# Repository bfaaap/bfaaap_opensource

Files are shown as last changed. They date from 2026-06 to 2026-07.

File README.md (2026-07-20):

# bFaaaP — a foot‑free piano pedal you can build 🎹

> 🌐 **English** · [日本語](i18n/ja/README.md) · [Deutsch](i18n/de/README.md)



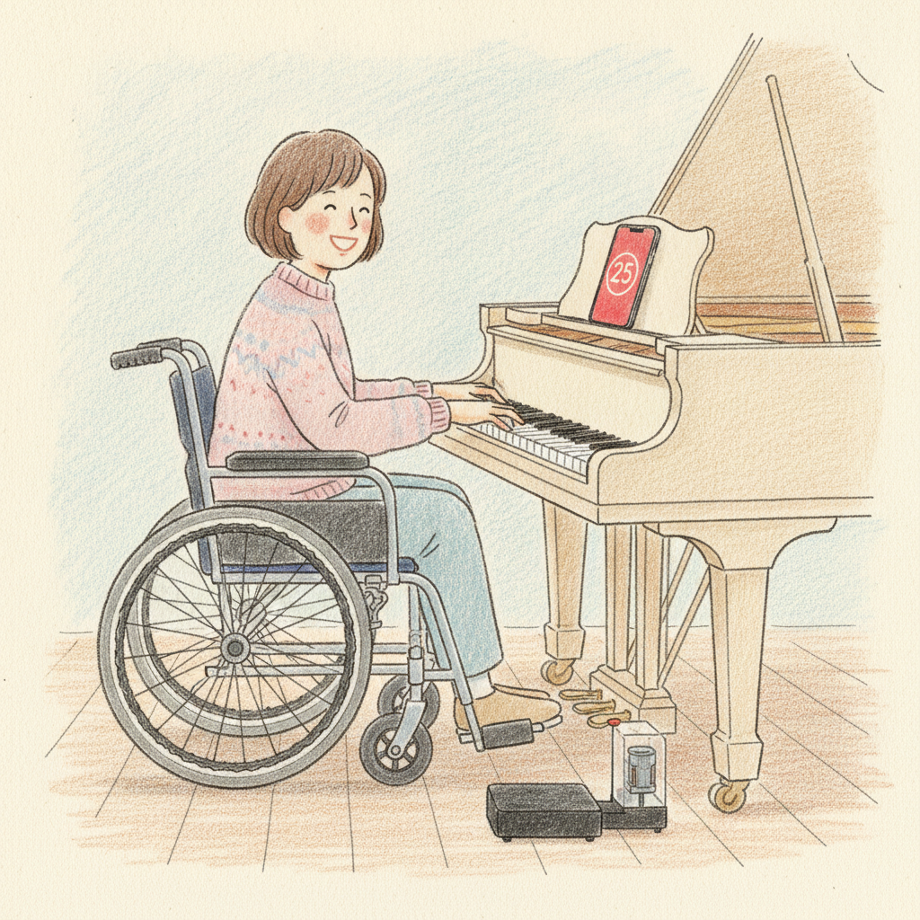
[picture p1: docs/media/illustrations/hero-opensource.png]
bFaaaP — play the pedal with a tilt of your head


> **bFaaaP** — *(**b**arrier‑**F**ree **a**ssist **a**s **a** **P**edal)* — is an **AI
> assistive piano‑pedal system**. Tilt your head a little and the sustain pedal goes down —
> **no feet needed.** An iPhone/iPad reads your head angle with on‑device AI and sends it over
> Bluetooth to a small device that presses (or switches) the piano's pedal.

It exists so that people who can't easily use a foot pedal — players with limb disabilities,
small children, the elderly, even a user with a tracheostomy — can play the piano with the
full expressive power of the pedal. And it's **open source**: this repository has everything
to build the device and run the controller **yourself**.

### Start here
🌱 **New?** → [**The bFaaaP story**](docs/story.md) · [How it works](docs/how-it-works.md) · [Glossary](docs/GLOSSARY.md)
🔧 **Make one** → [**Build it yourself**](docs/build/) (iOS · Pro · Switch)
🗂 **Find any source** → [Source map](docs/SOURCE-MAP.md) — which file / figure / code backs each topic
🙋 **Get help** → [Community Support](docs/ai-support.md) · 💛 [Support the project](SUPPORT.md)

> Status: this folder (`github_opensource/`) is the staging area being prepared for public
> release (see [`PUBLISHING-CHECKLIST.md`](PUBLISHING-CHECKLIST.md)). Docs are **English‑first**;
> Japanese & German will follow in `i18n/` subfolders.

---

## What is bFaaaP?

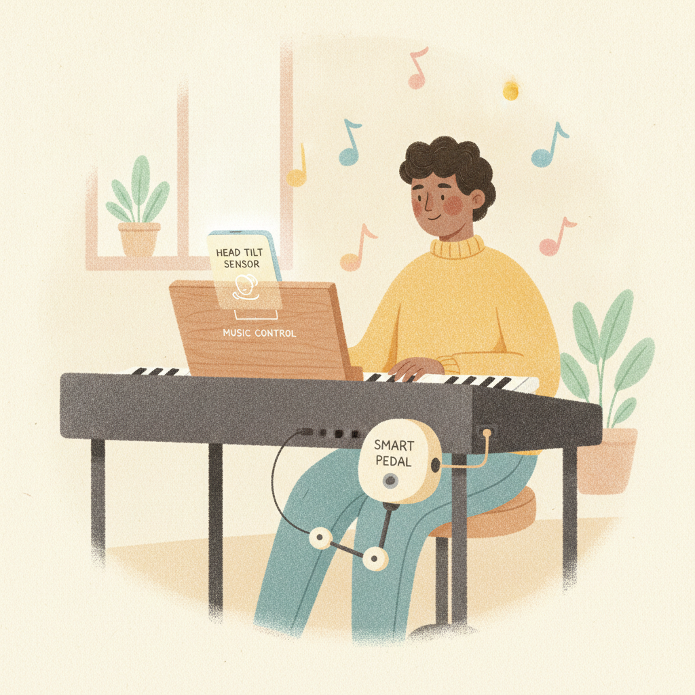
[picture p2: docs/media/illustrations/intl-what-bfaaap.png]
What is bFaaaP — a player using the head‑tilt sensor and smart pedal


A small head movement becomes a pedal press. You preset your own **offset (threshold)** — how far
to tilt — and a **multiplier**, and together they tune the pedalling to *you* — not just a crude
on/off. See [How it works](docs/how-it-works.md) for the friendly explanation.

## Two hardware lines, one app

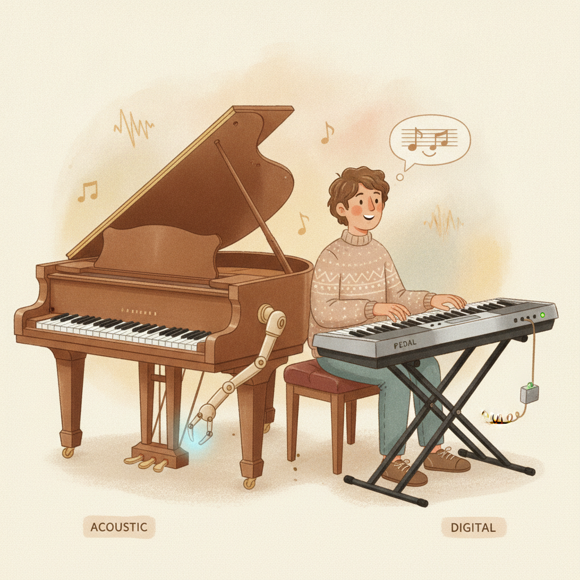
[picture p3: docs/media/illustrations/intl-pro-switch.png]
Pro for acoustic pianos, Switch for digital pianos


| Line | For | How it actuates |
|---|-----|---|
| 🎹 **bFaaaP Pro** | Acoustic pianos (**grand & upright**) | a **motor physically presses** the sustain pedal, anchored by an *airback* air‑cushion → [`device-pro-acoustic/`](device-pro-acoustic/) |
| 🎛️ **bFaaaP Switch** | **Electric pianos & keyboards** | plugs into the **sustain‑pedal jack** as an **electronic switch** (no motor/airback) → [`device-switch-electronic/`](device-switch-electronic/) |

The **same iOS app** ([`ios-app/`](ios-app/)) drives both lines; the Bluetooth protocol is identical.

## How it works

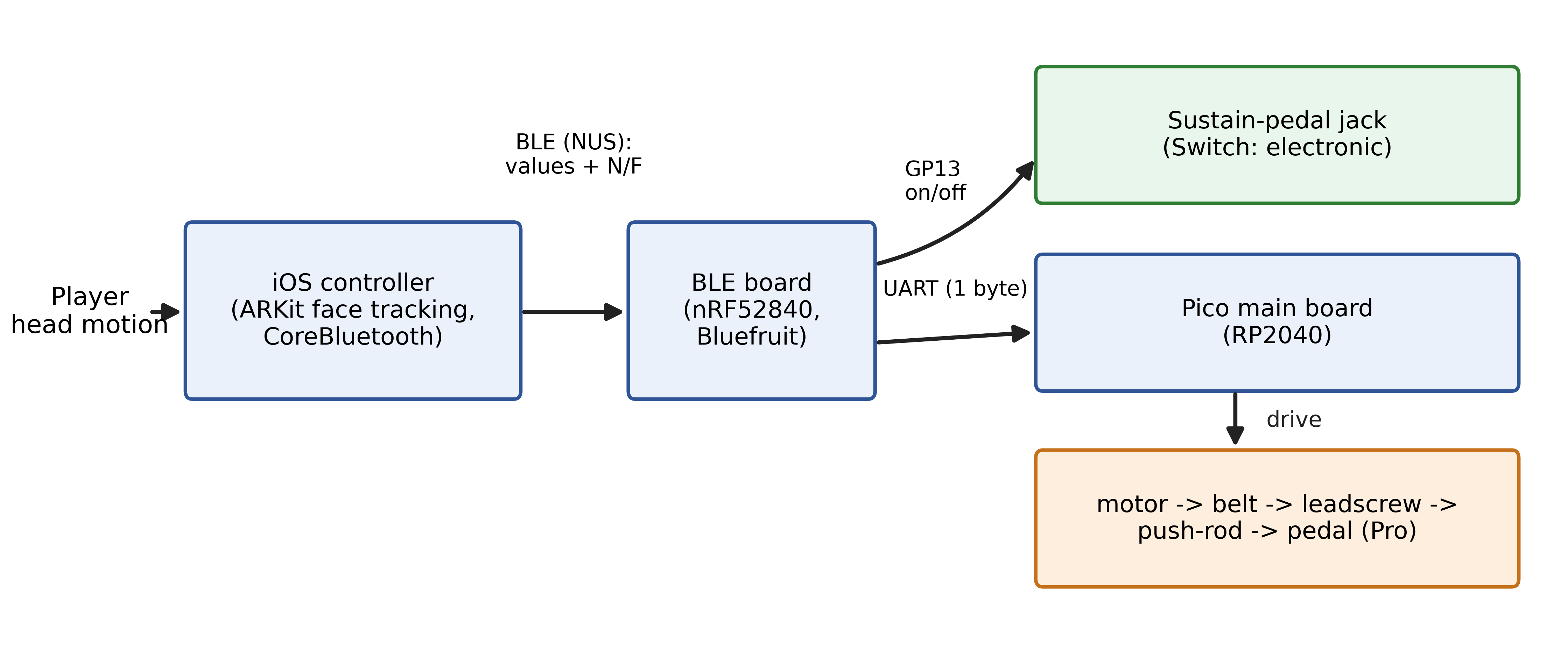
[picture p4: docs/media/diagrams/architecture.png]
System architecture


```
   Your head tilt
        │  ARKit / TrueDepth face tracking (iPhone/iPad AI)
        ▼
┌──────────────┐   BLE  "i00".."i99"   ┌─────────────────┐  UART  ┌──────────────┐  drive
│   iOS app    │ ────────────────────▶ │ BLE board nRF52  │ ─────▶ │  Pico RP2040 │ ─────▶ piano pedal
└──────────────┘                       └─────────────────┘        └──────────────┘
```

A key design point: ARKit produces head angles much faster than BLE should send them, so the
app **paces** the radio (a 100 ms timer + throttle) to keep the link solid — see
[`ios-app/DESIGN-HIGHLIGHTS.md`](ios-app/DESIGN-HIGHLIGHTS.md).

## Build it yourself

Open the **[Build hub](docs/build/)** and pick a track. The short version (Pro):

1. **Print & assemble** the mechanical parts — [`device-pro-acoustic/hardware/`](device-pro-acoustic/hardware/).
2. **Wire & flash** both boards — [`docs/toolchain/`](docs/toolchain/) (VS Code / PlatformIO / Arduino).
3. **Anchor** with the airback; set the travel limit.
4. **Build & install the iOS app** — [`ios-app/`](ios-app/) (your own signing team & bundle ID).
5. **Pair, calibrate, and play** — [`docs/operation/`](docs/operation/).

Stuck on any step? **[Ask in our community Q&A](docs/ai-support.md)** — the bFaaaP community and
team check each answer, so it's not instant.

### Bill of materials (overview, Pro line)
- iPhone / iPad with **TrueDepth** front camera (head tracking)
- **Raspberry Pi Pico** (main) + **nRF52840** BLE board (bridge)
- **IQ‑FORTIQ‑M42BLS‑100** motor *(reference v039B; EOL → closed‑loop **NEMA17‑class** successor
  under evaluation)*, belt‑coupled (**GT-2‑262 belt → T60/T60 pulleys, 1:1**) to a
  **vertical T10 lead‑screw** whose carriage drives a **push‑rod straight down** on the sustain
  pedal — all on a **2040 / 2080 / 4040 aluminium‑extrusion** frame
- **HX711** air‑pressure sensor, **2SK4017** MOSFET (pump), travel‑limit slider, **24 V PSU**
  *(self‑calibration uses motor **power**, not current — so supply voltage doesn't matter)*
- 3D‑printed parts (PLA+) + **airback** anchoring kit
- Full BOM & part numbers: [`device-pro-acoustic/hardware/PARTS-REFERENCE.md`](device-pro-acoustic/hardware/PARTS-REFERENCE.md)

> ⚠️ Some original parts are **EOL** (notably the IQ/Fortiq motor). Replacements & firmware tips:
> [`device-pro-acoustic/HARDWARE-AVAILABILITY.md`](device-pro-acoustic/HARDWARE-AVAILABILITY.md).

## The story, the people, the music 🎬

bFaaaP began in **2018** from one wheelchair user's wish to play the piano, and grew into a
team of engineers and musicians. Read the whole journey — with member introductions and **every
performance video** — in **[The bFaaaP story](docs/story.md)**.

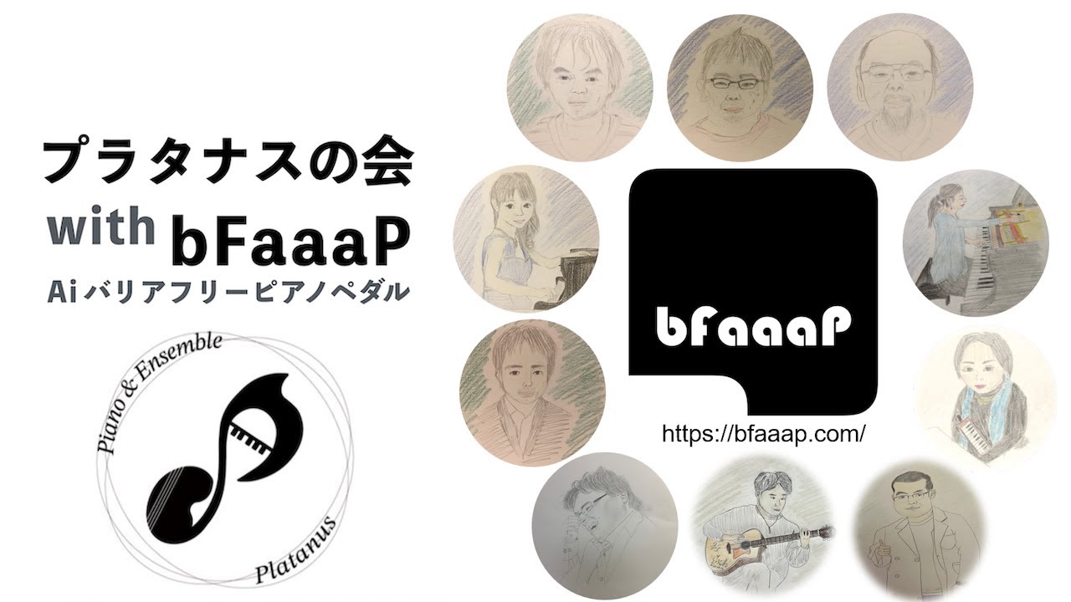
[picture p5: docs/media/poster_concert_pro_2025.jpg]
Platanus with bFaaaP — concert


- 📜 [History](docs/HISTORY.md) · 👥 [Members](docs/members/) · 💬 [Voices](docs/voices.md) · 🎥 [All videos](docs/videos/)
- ▶ **Best single demo** (grand piano, *with a setup walkthrough at 25:01*): <https://www.youtube.com/watch?v=V3cXeNW9jXY>

## 💛 Support

The devices aren't sold — your support keeps bFaaaP free and growing (development, community
support, parts/loaners, and inclusive concerts & lessons). See
[**SUPPORT.md**](SUPPORT.md) (PayPal now; Stripe — card / Apple Pay / Google Pay — coming) or use
the **Sponsor** button on this repo.

## 📣 Poster & events

Spread the word — here is the bFaaaP open‑source poster (front & back). Please feel free to print and share it.

<p align="center">
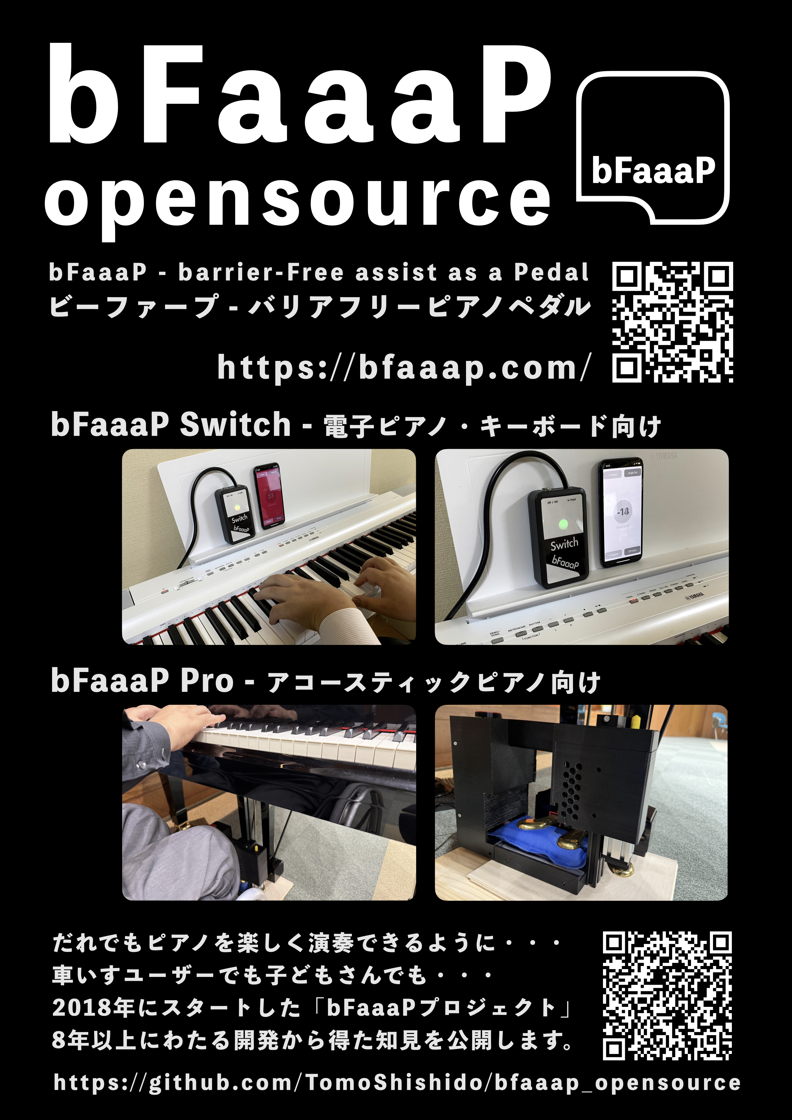
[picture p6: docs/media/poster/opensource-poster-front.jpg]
bFaaaP open‑source poster, front — the project, the Switch and Pro devices, and the QR codes
  
  <a href="docs/media/poster/opensource-poster-back.jpg">bFaaaP open‑source poster, back — the story since 2018, the 2025 Suzukake concert, and how to join</a>
</p>

<p align="center"><sub>Poster design: <b>Masahiro Ootaki</b> (Ootaki Architects Office)</sub></p>

> 📅 Thanks to the kind support of the **Tokyo Women's Choral Society**, this poster will be handed out at their **"Composer Exhibition Series Vol.6: Hideki Chihara"** concert on **Friday, July 31, 2026**. We're grateful for the chance to share our story — [concert details](https://tokyowomens-cs.website/2026/05/12/composerexhibitionseries-vol6-hidekichihara/).

## Repository layout

| Folder | Contents |
|---|---|
| [`ios-app/`](ios-app/) | iOS controller app — code, design notes, build guide, sanitized `src/`. Drives both lines. |
| [`device-pro-acoustic/`](device-pro-acoustic/) | **Pro** (acoustic): firmware, hardware (`cad/`, `3d-print/`, `airback/`, `schematic/`), motor info, assembly. |
| [`device-switch-electronic/`](device-switch-electronic/) | **Switch** (electric/keyboard): electronic‑sustain design (in progress). |
| [`docs/`](docs/) | Story, how‑it‑works, glossary, build hub, community support, architecture, operation, toolchain, videos, members, history. |
| [`bfaaap_arxiv_latex/`](bfaaap_arxiv_latex/) | The research **arXiv preprint** (LaTeX). |
| [`bfaaap_patent_info/`](bfaaap_patent_info/) | Plain‑language patent guide + prosecution files. |

## License

This project is **multi‑licensed by layer (adopted).** Full, verbatim texts are in
[`LICENSES/`](LICENSES/); the split (see [`LICENSE`](LICENSE)) is — **Apache‑2.0** (software: iOS
app, firmware; explicit patent grant), **CERN‑OHL‑W‑2.0** (hardware: CAD, 3D‑print, schematic),
**CC‑BY‑4.0** (documentation). Third‑party components keep their own licenses (e.g. the IQ module
library). Imported contributor materials (schematic / CAD / photos) are included **with consent**
(all members have consented — see [`PUBLISHING-CHECKLIST.md`](PUBLISHING-CHECKLIST.md)).

## 📄 Research

A LaTeX **arXiv** preprint (`main.tex`) is in [`bfaaap_arxiv_latex/`](bfaaap_arxiv_latex/). It
frames bFaaaP as inclusive design / human–machine interaction whose inventive core is a
**quantitative, user‑tunable head‑angle control law**, validated by a **human‑subject clinical
evaluation (APEE)**. Authors: T. Shishido (corresponding), M. Ootaki, H. Narusawa. *(A peer‑reviewed ACM
TACCESS version is maintained privately.)*

## Patents, trademark & design

The control method — a quantitative, user‑tunable control law in which the player presets an
angular **dead‑zone (offset)** (a range within which the actuator is not driven) and a
**multiplier**, which together fix a secondary, temporal **response speed** (how fast the actuator
follows the head past the dead‑zone) — is patented. **Two patents are in force in Japan**, with an English **PCT**
as priority basis:

| Kind | Number | Title | Link |
|---|---|---|---|
| Patent (JP) | **特許第6726319号** — JP 6726319 B2 | Auxiliary pedal system | <https://patents.google.com/patent/JP6726319B2/en> |
| Patent (JP) | **特許第7004771号** — JP 7004771 B2 | Device controller | <https://patents.google.com/patent/JP7004771B2/en> |
| PCT (EN, priority) | **WO 2019/176164** | Auxiliary pedal system | <https://patentscope.wipo.int/search/en/detail.jsf?docId=WO2019176164> |

Inventors: H. Narusawa, M. Ootaki, T. Shishido, K. Yamaguchi, D. Tokushige. **bFaaaP®** is a
registered trademark; the glasses‑mounted motion sensor is a registered design. Full prosecution
file & a plain‑language guide: [`bfaaap_patent_info/`](bfaaap_patent_info/).

### Patent licensing
Licensing generally **depends on the intended embodiment**. However, **for uses with a genuinely
public, open purpose the authors intend to grant a licence free of charge** — in particular **for
products/services (even commercial) that help people with disabilities participate more
inclusively, bFaaaP patent licensing is, as policy, free.** If that fits your use, please contact
**Tomoyuki Shishido** (ORCID <https://orcid.org/0000-0002-8944-2088>).

## Credits

Developed by **Tomoyuki Shishido** and the bFaaaP / **Platanus** members (incl. M. Ootaki,
H. Narusawa, and others — see [Members](docs/members/)). The iOS app is **free** on the App Store as
**bFaaaP Pro & Switch**. Illustrations by **Saki Shiokawa** and the bFaaaP project (AI‑assisted).

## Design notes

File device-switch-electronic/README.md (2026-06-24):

# bFaaaP Switch — for electric pianos & keyboards

The **Switch** line targets **electric pianos and keyboards**. Instead of a motor
physically pressing an acoustic pedal (the Pro approach), it actuates the
instrument's sustain **electronically**: it plugs into the digital piano /
keyboard's **sustain‑pedal jack** and acts as the pedal **switch** (closing /
opening the sustain circuit on command).

Because there is **no motor, no lead screw, and no airback**, the Switch is much
simpler than the Pro — essentially the **BLE board on its own** (an **Adafruit
ItsyBitsy nRF52840 Express**), using its direct on/off output (the firmware drives
`GP13` on `N`/`F`). The standalone Switch firmware now lives here in
[`firmware/`](firmware/) (the same nRF52 BLE-board code as the Pro, minus the
motor-board bridge). The board's **onboard DotStar RGB LED** shows the engage
state as a colour on the device itself (mirroring the app's white→red indicator).

The **same iOS app** drives this line — identical head‑angle tracking and BLE
protocol as the Pro (`N` engage / `F` release; `iNN` is unused for a simple
on/off switch). When the player tilts past the threshold the app's indicator
turns **red** and the sustain engages; head up → released.

> Demo (electric piano): <https://www.youtube.com/watch?v=Im4jsed1tJQ>
> · Project site: <https://bfaaap.com>

## How it works

```
 iOS app ──BLE (N / F)──▶ BLE board (nRF52) ──GP13 on/off──▶ MOSFET
                                                              │
                                                              ▼
                                              digital piano sustain‑pedal jack
```

A **ROHM `RU1J002YN`** N-channel (logic-level) **MOSFET** on the BLE board's `GP13`
output bridges the sustain jack's contacts (confirmed by Narusawa, 2026‑06‑24 —
**no series resistor**) — the same wiring most digital pianos expect from a normal
momentary sustain pedal (tip/sleeve). Polarity / normally‑open vs normally‑closed
is handled by the on‑type / off‑type setting (`n` / `f`).

## Connection & certification

- The device cable ends in a **6.3 mm 2‑pole (TS) phone plug**; it plugs into the
  electric piano's **SUSTAIN** pedal jack (3‑pedal "PEDAL UNIT" jacks differ).
- The shipped Switch device carries Japan radio certification **技適 R018‑180280**.
- **On‑type / Off‑type**: some pianos invert the sustain logic — flip it with the
  app's On/Off button.
- Full end‑user steps: [`../docs/user-manual/`](../docs/user-manual/) ·
  manual video <https://youtu.be/XOVENtBsOp4>.

## Status

The **firmware is now in the repo** — see [`firmware/`](firmware/) for the
standalone nRF52 sketch (`bFaaaPSW_20211007_for_ex_fs_J_13_ymc`), its full BLE
command protocol, the GP13 on/off behaviour, channel selection, and power
management. The **hardware** around it is now specified too:

```
device-switch-electronic/
├── firmware/    ✅ standalone BLE-board firmware (on/off via GP13)   ← added 2026-06-24
├── hardware/    ✅ RU1J002YN low-side MOSFET + reference schematic   ← added 2026-06-24
└── assembly/    ◑ AI-draft enclosure: parametric SCAD + STL + drawing ← added 2026-06-24
```

**Confirmed by Narusawa (2026‑06‑24):** board = **ItsyBitsy nRF52840 Express**; the
GP13 switching element is a **ROHM `RU1J002YN`** N-channel logic-level MOSFET (no
series resistor); **no A1 button** — power on / wake with **RESET**; powered by
**2× AA cells** (battery level shown by the **DotStar dimming**); the 2021‑10‑07
firmware is **final**. The Switch hardware is now **fully specified** — the
reference schematic (RU1J002YN low‑side switch) is in [`hardware/`](hardware/), and
an **AI-draft 3D-printable enclosure** (parametric OpenSCAD + STL + drawing) is in
[`assembly/`](assembly/) — *untested; verify against your parts before printing*.

See the shared [`../docs/architecture/`](../docs/architecture/) for the BLE
protocol and [`../ios-app/`](../ios-app/) for the controller.

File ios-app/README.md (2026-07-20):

# iOS controller app (bFaaaP Pro & Switch)

The SwiftUI app that reads the user's head angle (ARKit / TrueDepth) and streams
it over Bluetooth LE to the pedal device.

**One app, both hardware lines.** The same iOS app drives **bFaaaP Pro** (for
acoustic pianos) and **bFaaaP Switch** (for electric pianos / keyboards). The
BLE protocol is identical; only the device hardware differs.

## Contents

| File / folder | What |
|---|---|
| [`CODE-STRUCTURE.md`](CODE-STRUCTURE.md) | How the Swift files fit together + data flow |
| [`DESIGN-HIGHLIGHTS.md`](DESIGN-HIGHLIGHTS.md) | The clever bits (AR↔BLE timing, hysteresis, …) |
| [`BLE-CONNECTION-FLOW.md`](BLE-CONNECTION-FLOW.md) | Flowcharts: recognize device by name (4 channels), connect, and the sync→async handoff |
| [`BUILD.md`](BUILD.md) | How to build it yourself (set your own team & bundle ID) |
| [`src/`](src/) | The Xcode project (sanitized: blank team, placeholder bundle ID) |
| [`app-store/`](app-store/) | App Store listing info, icon & screenshots ([on the App Store](https://apps.apple.com/app/id1545866059)) |

## App facts

| Item | Value |
|---|---|
| Display name | **bFaaaP Pro & Switch** (on‑device + App Store; Xcode target stays `bFaaaPSwitch1`) |
| Bundle ID (in repo) | `com.example.bfaaap` (placeholder — set your own) |
| Min iOS | 14.5 |
| Language / UI | Swift 5, SwiftUI |
| Key frameworks | ARKit (face tracking), CoreBluetooth (BLE) |
| Requires | Device with a TrueDepth front camera |

Start with [`CODE-STRUCTURE.md`](CODE-STRUCTURE.md), then
[`DESIGN-HIGHLIGHTS.md`](DESIGN-HIGHLIGHTS.md), then build via [`BUILD.md`](BUILD.md).

---
**License (adopted):** the iOS app source is released under the **Apache License 2.0** (explicit patent grant). See [`../LICENSE`](../LICENSE).

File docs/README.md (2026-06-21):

# Documentation (shared)

Cross‑cutting docs that apply to both hardware lines and the iOS app.

- [`architecture/`](architecture/) — how the system works end to end: signals,
  BLE / Nordic UART protocol, the AR→BLE timing model.
- [`operation/`](operation/) — how to set up and operate the system day to day.
- [`toolchain/`](toolchain/) — VSCode‑centric guide to **flashing the boards**
  (nRF52 + RP2040), testing/running, and **3D‑print slicing**.
- [`user-manual/`](user-manual/) — end‑user manual (connect, channel, on/off‑type,
  angle threshold) adapted from the public manual.
- [`HISTORY.md`](HISTORY.md) — how bFaaaP started (2018) and evolved.
- [`members/`](members/) — the people behind bFaaaP (with caricatures).
- [`videos/`](videos/) — guide to all YouTube videos, by category (concerts,
  setup, manual, promotion), newest first.
- [`../bfaaap_patent_info/`](../bfaaap_patent_info/) — the **patents**: the English
  PCT, the two granted Japanese patents, prior‑art citations, and a plain‑language
  [patent guide](../bfaaap_patent_info/general_description/README.md) (procedure
  diagrams, dated prosecution histories, academic take‑aways).

Line‑specific build/assembly lives with each device, e.g.
[`../device-pro-acoustic/assembly/`](../device-pro-acoustic/assembly/).

iOS code documentation is in [`../ios-app/`](../ios-app/)
(`CODE-STRUCTURE.md`, `DESIGN-HIGHLIGHTS.md`, `BUILD.md`).

> Localization: English first; Japanese and German versions are planned in
> separate `i18n/` subfolders.

---
**License (adopted):** documentation is released under **CC‑BY‑4.0**. See [`../LICENSE`](../LICENSE).

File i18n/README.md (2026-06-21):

# Translations / 翻訳 / Übersetzungen

The project documentation is written **English‑first** (repo root + [`../docs/`](../docs/)).
Translated mirrors live here:

- 🇯🇵 **日本語** → [`ja/`](ja/) — start at [`ja/README.md`](ja/README.md)
- 🇩🇪 **Deutsch** → [`de/`](de/) — start at [`de/README.md`](de/README.md)

Each translated page has a 🌐 language switcher at the top. **Images, figures, code, CAD, and
schematics are not translated** — the translated pages link back to the shared assets in
[`../docs/media/`](../docs/media/) and the source folders, so there is a single source of truth.

> Translations are maintained by hand (kept in step with the English originals). If a page
> isn't translated yet, its links fall back to the English version.

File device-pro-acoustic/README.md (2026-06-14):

# bFaaaP Pro — pedal driver for acoustic pianos

The **Pro** device physically presses an acoustic piano's **sustain (damper)
pedal** on command from the iOS app. A servo motor pushes the pedal; a 3D‑printed
frame holds everything in place over the pedals; an **airback** anchoring
mechanism keeps the whole unit from sliding under the motor's reaction force.

> For electric pianos / keyboards, see the sibling line
> [`../device-switch-electronic/`](../device-switch-electronic/) (planned).

## Contents

| Folder | What |
|---|---|
| [`firmware/`](firmware/) | RP2040 / Raspberry Pi Pico firmware + the IQ motor library |
| [`hardware/`](hardware/) | Mechanical design: `cad/` (FreeCAD), `3d-print/` (STL/3MF), `airback/`, **`schematic/`** (circuit), **`reference/`**, `enclosure-labels/` |
| [`hardware/PARTS-REFERENCE.md`](hardware/PARTS-REFERENCE.md) | **Authoritative parts list** (boards, motor, connectors) with vendor links |
| [`motor/`](motor/) | Which motor to use + links to vendor docs |
| [`assembly/`](assembly/) | Build guide & bill of materials |
| [`HARDWARE-AVAILABILITY.md`](HARDWARE-AVAILABILITY.md) | ⚠️ EOL parts (IQ motor) + current replacements + firmware‑adaptation tips + links |
| [`DISCORD-FINDINGS.md`](DISCORD-FINDINGS.md) | Engineering summary from the team Discord + co‑author Q&A (parts, calibration, dev env, next‑gen ideas) |

## How a press happens

1. The iOS app sends `N` (engage) / `iNN` (amount) / `F` (release) over BLE.
2. The Pico firmware drives the **IQ / Fortiq** servo motor to push the sustain
   pedal proportionally.
3. The **airback** (inflated once at setup) keeps the unit anchored so the motor
   pushes the pedal — not itself — away. See
   [`hardware/airback/`](hardware/airback/).

See [`../docs/architecture/`](../docs/architecture/) for the signal/BLE detail
and [`../docs/operation/`](../docs/operation/) for how to operate it.

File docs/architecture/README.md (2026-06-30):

# Architecture

> 🌐 **English** · [日本語](../../i18n/ja/docs/architecture/README.md) · [Deutsch](../../i18n/de/docs/architecture/README.md)

## Signal chain

1. **Head tracking (iOS).** The controller app uses ARKit `ARFaceTrackingConfiguration`
   (TrueDepth camera) to read the user's head pitch angle.
2. **Mapping.** The head angle, minus the user's **offset** (dead‑zone), is multiplied by a user
   **"multiplier"** (slider, 0–20) and clamped to `0–99`. The offset and multiplier together fix a
   secondary **response speed** (how fast the actuator follows the head past the dead‑zone) — the
   patented "key."
3. **Transmission (BLE).** The value is sent as an ASCII string `i00`–`i99` over a
   **Nordic UART Service (NUS)**. Engage/release transitions also send marker
   bytes `N` (on) and `F` (off).
4. **Actuation (device).** The Pico firmware parses the value and commands the
   **IQ / Fortiq** motor to press the sustain pedal proportionally.

## BLE details (observed)

| Item | Value |
|---|---|
| Service (NUS) | `6E400001-B5A3-F393-E0A9-E50E24DCCA9E` |
| Write (RX, app→device) | `6E400002-B5A3-F393-E0A9-E50E24DCCA9E` |
| Notify (TX, device→app) | `6E400003-B5A3-F393-E0A9-E50E24DCCA9E` |
| Also present | DFU `00001530-…`, Device Information `180A`, Battery `180F` |
| Advertised name | `bFaaaPSwitch_1` (renameable `_1`..`_4` for multiple devices/channels) |

The app filters on the advertised local name so it connects only to a
`bFaaaPSwitch_n` device and ignores other nearby peripherals.

## Payload format

- `iNN` — target value, `NN` = `00`..`99` (angle × multiplier, clamped).
- `N` — engage signal (pedal active).
- `F` — release signal (pedal returns to neutral).
- Values are streamed on a timer (~100 ms cadence in current firmware/app).

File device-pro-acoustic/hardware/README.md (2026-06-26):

# Hardware — bFaaaP Pro (acoustic)

The mechanical assembly that holds the motor over the piano's pedals, drives the
sustain pedal, and anchors itself against the reaction force.

```
hardware/
├── cad/               FreeCAD source files (.FCStd) — editable design
├── 3d-print/          Ready-to-print meshes (.stl) and slicer projects (.3mf)
├── airback/           Anchoring mechanism (air bag + pump + hand controller)
├── schematic/         Circuit schematic + block/power diagrams (by Taguchi)
├── reference-design/  AI-draft adaptable architecture + mechanical layout (simplified)
├── photos/            Real build photos (airback + drive unit; by Taguchi)
└── enclosure-labels/  Product / enclosure label artwork (review before publishing)
```

> 🧭 **New to the Pro?** Start with the **[`reference-design/`](reference-design/)** —
> an AI-draft, *adaptable* system architecture + mechanical layout that explains how the
> whole device fits together (and what you can simplify or swap).

> 📷 **Build photos** of the airback and drive unit are in
> [`photos/`](photos/) (from the team Discord).

> 📐 **Wiring:** a **single‑sheet KiCad schematic** of the whole Pro device (IQ /
> v039B reference generation) is in [`schematic/`](schematic/), together with the
> system block diagram and the power‑supply options. It gives the authoritative
> **Pico pin map** (BLE UART GP0/GP1; HX711 GP2/GP3; IQ‑motor serial GP4/GP5;
> air‑pump MOSFET GP12; slider potentiometer on **ADC0/GP26**) and the **two power
> rails (+5 V logic, +24 V motor)**.

## Major components

| Component | What it does | Where |
|---|---|---|
| **Controller board** | Raspberry Pi Pico (RP2040) + BLE (Nordic UART). Receives `iNN`/`N`/`F` and commands the motor. | [`../firmware/`](../firmware/) |
| **Motor** | **IQ‑FORTIQ‑M42BLS‑100** (100 W) — **current reference (v039B)**; EOL → successor is a **closed‑loop stepper with a DRV8825‑compatible interface** (DRV8825 itself = old standard module, early tests only). | [`../motor/`](../motor/) |
| **Drivetrain** | Motor → **GT-2‑262 timing belt** + **T60 pulleys** → **T10 lead screw** (~150 mm) → push‑rod. Bearings: flanged + thrust + collar. | `cad/`, BOM in [`../assembly/`](../assembly/) |
| **Frame** | **Aluminium extrusion** (4040 / 2040 / 2080) + T‑slot/2020 brackets, with 3D‑printed parts (PLA+). | `cad/`, `3d-print/` |
| **Hand controller** | A small box with a **travel‑limit slide potentiometer ("slide volume")** + pump on/off + switch. The [schematic](schematic/) wires it as a potentiometer (wiper → **ADC0/GP26**) plus a push switch. *(Per the device co‑author: the slide volume is correct; the **RJ45/LAN socket on the body is currently unused** — legacy.)* | [`airback/`](airback/), [`schematic/`](schematic/) |
| **Airback** | A stock **WINBAG air jack** (160 × 150 mm, ≤50 mm, 135 kg) under a neighbouring pedal; inflated by its **manual bulb** or an electric **air pump on GP12** (2SK4017 MOSFET); keeps the unit from moving under the motor's reaction force. | [`airback/`](airback/) |

## Workflow

- Edit the design in **FreeCAD** using the `cad/` sources.
- Export / slice to the meshes in `3d-print/` for printing.
- The `.3mf` files include slicer settings used for reference prints.

## Notes / TODO

- Print material/orientation/supports: document recommended settings.
- Wiring (motor ↔ Pico) and the airback pump/controller schematic: to be added.
- Reconcile CAD ↔ STL revisions and add a per‑part index before publishing.

---
**License (adopted):** the hardware designs (CAD, 3D‑print files, schematic) are released under **CERN‑OHL‑W‑2.0**. Imported schematic/CAD/photos by Taguchi are included **with consent (2026‑06‑18)**. See [`../../LICENSE`](../../LICENSE).

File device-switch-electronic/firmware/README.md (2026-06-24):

# Switch firmware (standalone BLE on/off)

The **Switch** device needs **only one board** — the **nRF52 BLE board** — because
it actuates a digital piano's sustain **electronically** (no motor, no Pico, no
airback). This is the firmware that runs on it.

> Firmware by **Hiroyuki Narusawa**. Contributed for the open-source release on
> 2026-06-24; sketch dated **2021-10-07**.

## Sketch

| Sketch | Board | Role |
|---|---|---|
| [`bFaaaPSW_20211007_for_ex_fs_J_13_ymc/`](bFaaaPSW_20211007_for_ex_fs_J_13_ymc/) | **nRF52** (Adafruit Bluefruit) | **Standalone Switch** — BLE in → on/off the sustain line on **GP13**. |

> The folder name matches the `.ino` name so it opens directly in the Arduino IDE.
> `for_ex_fs` = "for **ex**ternal **f**oot **s**witch"; `J_13` = the on/off output
> is **pin 13 (GP13)**; the trailing tag is the maker's initials.

### Relationship to the Pro BLE board

This is the **same nRF52 BLE-board code family** as the Pro's
[`bFaaaPpro_BLE_2024010309_bord_A.ino`](../../device-pro-acoustic/firmware/pico/bFaaaPpro_BLE_2024010309_bord_A.ino),
but **standalone**: it keeps the `N`/`F` direct on/off on **GP13** and **omits**
the `iNN`→`Serial1` proportional bridge to a Pico (the Switch has no motor board).
Same Nordic UART Service, same `bFaaaPSwitch_1…4` advertising names, same channel
storage — so the **same iOS app** drives either line unchanged.

## Board

**Adafruit ItsyBitsy nRF52840 Express** (Bluefruit / Nordic nRF52840). Evidence in
the sketch: the **onboard DotStar** RGB LED is driven on `DATAPIN 8 / CLOCKPIN 6`,
the wake pin is `PIN_A1`, and the switched output is `13`. This DotStar/ItsyBitsy
board is specifically the **Switch** line's board — the **Pro** uses the Akizuki
**AE‑NRF52840** (Feather alternative) and has no LED routine (confirmed by Taguchi,
2026‑06‑24).

Libraries: `bluefruit.h` (Adafruit nRF52 / Bluefruit), `Adafruit_LittleFS` +
`InternalFileSystem` (stores the channel), `Adafruit_DotStar` (status LED).

## BLE

- **Service:** Nordic UART Service (NUS)
  - Service UUID `6e400001-b5a3-f393-e0a9-e50e24dcca9e`
  - Characteristic `6e400002-b5a3-f393-e0a9-e50e24dcca9e`
- Also exposes **OTA DFU** (`BLEDfu`), **Device Information** (`BLEDis`:
  manufacturer "bFaaaP factory", model "pFaaaPSwitch") and **Battery** (`BLEBas`,
  currently written as a fixed `100`).
- TX power `-4 dBm`; advertising interval `32–244 × 0.625 ms` (≈ 20–152 ms);
  fast-advertise timeout 30 s; advertising restarts on disconnect.

## Command protocol (single ASCII bytes over NUS)

The iOS app writes one byte at a time:

| Byte | Char | Action |
|---|---|---|
| `0x4E` | `N` | **Engage** sustain — `GP13` HIGH in *on-mode* / LOW in *off-mode* |
| `0x46` | `F` | **Release** sustain — `GP13` LOW in *on-mode* / HIGH in *off-mode* |
| `0x6E` | `n` | Set **on-mode** (normal polarity) |
| `0x66` | `f` | Set **off-mode** (inverted polarity — for pianos with reversed sustain logic) |
| `0x57` | `W` | Select **channel 1** (advertise as `bFaaaPSwitch_1`), then deep-sleep to reboot |
| `0x58` | `X` | Select **channel 2** (`bFaaaPSwitch_2`), then deep-sleep |
| `0x59` | `Y` | Select **channel 3** (`bFaaaPSwitch_3`), then deep-sleep |
| `0x5A` | `Z` | Select **channel 4** (`bFaaaPSwitch_4`), then deep-sleep |
| `0x50` | `P` | **Power off** (deep sleep) |

> A commented-out `C…/` command (set the status-LED colours from an RGB string) is
> present but disabled. There is **no `iNN` / motor path** in this sketch.

## Output → sustain jack

`GP13` is the on/off output. For a digital piano you bridge the instrument's
**sustain-pedal jack** (commonly a 6.3 mm / TS jack) with a **ROHM `RU1J002YN`**
N-channel MOSFET driven from `GP13` (confirmed by Narusawa, 2026‑06‑24 — *not* a
relay or optocoupler), with **no series resistor** on the sustain line. The
`RU1J002YN` is a **0.9 V-drive logic-level** part (Vgs(th) = 0.3–0.8 V; 50 V /
±200 mA; R_DS(on) ≤ 2.2 Ω; **UMT3F / SOT-323FL** package with a built-in ESD
protection diode — [ROHM datasheet](https://www.rohm.com/products/transistors/mosfets/standard/ru1j002yn-product)),
so the **3.3 V `GP13`** output drives it fully on. The **on-mode / off-mode**
(`n`/`f`) selects normally-open vs normally-closed so it matches the host
instrument's polarity.

> Wiring: a standard **low-side switch** — gate ← `GP13`, **drain → sustain-jack
> tip**, **source → GND** (= jack sleeve), **no series resistor**. Full reference
> schematic (Narusawa, 2026‑06‑24): [`../hardware/`](../hardware/).

## Channels (run several at once)

Up to **four** identities `bFaaaPSwitch_1…4` let you pair multiple Switch devices
(or distinguish pedals) without collision. The selected channel is stored in the
nRF52's internal LittleFS file `/W.txt` and applied on the next boot.

## Status LED (onboard DotStar)

The single onboard DotStar mirrors the app's indicator: a slow **blink while
advertising / waiting**, a steady colour **when connected / released**, and a
different colour **while the sustain is engaged**. Brightness drops once connected.

## Power management

- **Deep sleep** (`sd_power_system_off`) when: no central connects within ~30 s of
  power-on; on the `P` command; on a channel change; or when the **A1 button is
  held LOW for ≥ 5 s**.
- **Wake:** the firmware wakes on **`A1` → GND** (`INPUT_PULLUP_SENSE`), **but the
  shipped Switch has no A1 button** (confirmed by Narusawa, 2026‑06‑24) — you
  **power on / wake it with the board's RESET button**. The A1 code path is
  optional/unused in the built device.
- **Battery:** **2× AA cells** (replaceable primary cells — *not* a USB-charged
  LiPo; confirmed by Narusawa, 2026‑06‑24). Remaining charge is **shown by the
  onboard DotStar dimming** as the cells deplete (no numeric fuel gauge —
  consistent with the firmware writing a fixed `100%` over BLE).

## Build / flash

Install the **Adafruit nRF52** board support, double-tap **RESET** to enter the
UF2 bootloader, and upload the sketch. Full VSCode/Arduino steps:
[`../../docs/toolchain/`](../../docs/toolchain/). The on-the-wire BLE protocol is
shared with the controller — see [`../../docs/architecture/`](../../docs/architecture/)
and the [iOS app](../../ios-app/).

## Hardware — confirmed by Narusawa (2026-06-24)

- **Board:** Adafruit **ItsyBitsy nRF52840 Express** (confirmed).
- **Switching element on GP13:** a **ROHM `RU1J002YN`** N-channel logic-level MOSFET (not a relay/opto).
- **Sustain line:** **no series resistor**; polarity handled by on/off-mode (`n`/`f`).
- **Controls:** **no A1 button** — power on / wake with the **RESET** button.
- **Power:** **2× AA cells** (replaceable, not USB-rechargeable); battery level
  shown by the **DotStar dimming** (no numeric gauge).
- **Firmware:** the **2021-10-07** sketch is the **final/current** version.

## Reproduction status — complete ✅

The Switch hardware is **fully specified** — nothing blocks a rebuild. The switching
MOSFET is the **ROHM `RU1J002YN`** wired as a low-side switch (no series resistor);
the full **reference schematic** (Narusawa, 2026‑06‑24) is in
[`../hardware/`](../hardware/).

---
**License (adopted):** firmware is released under the **Apache License 2.0**
(explicit patent grant). See [`../../LICENSE`](../../LICENSE).

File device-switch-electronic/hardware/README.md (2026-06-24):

# Switch hardware — the sustain switch

The Switch needs **one transistor** between the BLE board's `GP13` output and the
instrument's sustain‑pedal jack: a **ROHM `RU1J002YN`** N‑channel logic‑level MOSFET
wired as a **low‑side switch**. Reference schematic by **Hiroyuki Narusawa**
(2026‑06‑24).

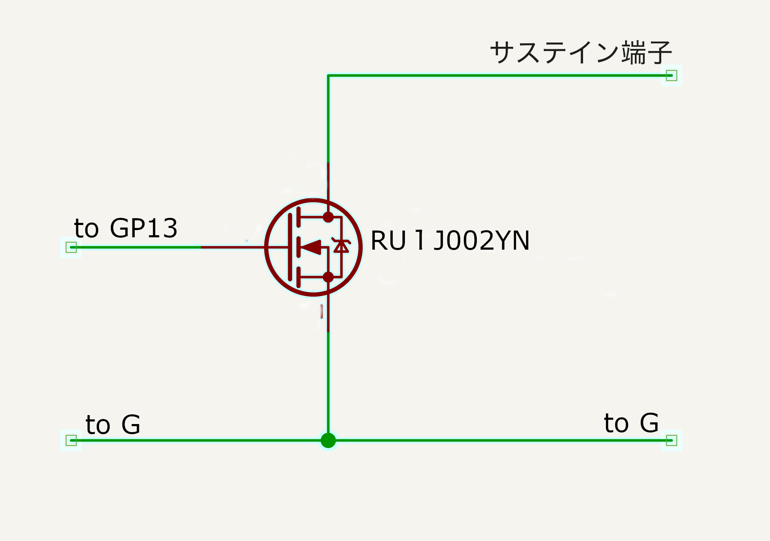
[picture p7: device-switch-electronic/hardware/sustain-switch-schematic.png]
bFaaaP Switch sustain-switch reference schematic — RU1J002YN low-side MOSFET


*(The one Japanese label, サステイン端子, = "sustain‑pedal terminal".)*

## Wiring

```
                Sustain jack (tip)
                       │
                       │  Drain
                    ┌──┴──┐
   GP13 ───── Gate ┤  Q1  │   RU1J002YN  (N-channel, logic-level;
                    └──┬──┘   body + ESD diodes internal)
                       │  Source
                       ●──── GND   ( = the sustain jack's sleeve / ground )
```

- **Gate ← `GP13`** (from the nRF52 BLE board). No series / gate resistor.
- **Drain → sustain‑jack tip** (the "sustain" signal of the digital piano).
- **Source → GND**, shared with the **sustain jack's sleeve** and the board ground.
- The RU1J002YN's **body diode and gate ESD diode are internal** — no extra parts.

## How it switches

`GP13` HIGH → the MOSFET turns **on** → it pulls the **sustain tip down to GND**,
which most digital pianos read as **"pedal pressed"** (sustain engaged). `GP13` LOW
→ MOSFET **off** → the tip floats → **released**.

Because the part is **logic‑level** (Vgs(th) ≈ 0.3–0.8 V; full 0.9 V drive), the
**3.3 V `GP13`** turns it fully on. The app's **on‑type / off‑type** toggle
(`n` / `f` in the firmware) flips the polarity for instruments whose sustain logic
is inverted.

> This is the whole "Switch" hardware: the **BLE board + this one MOSFET**. See the
> firmware in [`../firmware/`](../firmware/) for the BLE protocol and pin behaviour,
> and the device overview in [`../README.md`](../README.md).

---
**Credits:** reference schematic © **Hiroyuki Narusawa** (bFaaaP team). Part
datasheet is ROHM's (vendor copyright) — see the official
[ROHM RU1J002YN page](https://www.rohm.com/products/transistors/mosfets/standard/ru1j002yn-product).

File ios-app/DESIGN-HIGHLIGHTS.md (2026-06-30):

# iOS app — design highlights (the clever bits)

> 日本語・ドイツ語版は後日 `i18n/` 配下に追加予定（English first）.

This file explains the non‑obvious engineering decisions that make bFaaaP feel
responsive and reliable. They are the parts worth understanding before changing
the code.

---

## 1. Decoupling AR sampling rate from BLE send rate  ★ most important

**Problem.** ARKit face tracking delivers a new head angle on every camera
frame (~60 fps, every ~16 ms). Bluetooth LE on this link cannot reliably absorb
60 writes per second — pushing every frame floods the channel and causes
stalls, lag, and dropped/garbled messages on the device side.

**Solution — sample, don't stream.** The AR delegate never sends the continuous
value directly. It only writes the latest angle into a shared variable:

```swift
// ARKitAngleDetection.session(_:didUpdate:)
self.leftY = leftYRadian.radiansToDegrees     // just store it, ~60 fps
```

The radio traffic is paced separately by a **100 ms timer** in `PlayView`,
which samples whatever the latest angle is and sends one message:

```swift
// PlayView.startTimer()  — fires every 0.10 s (10 Hz)
let v = min(99, Int(max(0, (-leftY) - Float(globalOffset)) * multiplier))
bleManager.sendString(sendText: String(format: "i%02d", v))   // "i00".."i99"
```

So AR runs fast, BLE runs slow, and they meet through one shared variable. The
sender is rate‑limited to a comfortable 10 Hz regardless of camera speed.

**History / tuning.** The interval was originally as low as **5 ms** and was
deliberately raised to **100 ms** after real‑device testing, because the faster
cadence produced communication bugs. In other words: *the AR extraction is
faster than BLE can transmit, so a delay is inserted to keep the iOS↔device
communication bug‑free.* This single decision is the backbone of the system's
stability.

The discrete on/off events use the same principle with a tighter guard
(`> 0.01 s`, i.e. 10 ms) so a press/release is never sent more than ~once per
10 ms.

## 2. Hysteresis on pedal engage/release (no chatter)

A pedal that toggles every time the angle wobbles across the threshold would
buzz. The engage and release thresholds are intentionally **different**:

```swift
if (-Int(leftY) >= globalOffset)      && pedalState == .off { send "N"; .on }
if (-Int(leftY) <  globalOffset - 1)  && pedalState == .on  { send "F"; .off }
```

The `- 1` creates a small **dead band**, and the `pedalState` guard makes the
events **edge‑triggered** (exactly one `N` per press, one `F` per release).
Together they eliminate chatter around the threshold.

## 3. Angle → value mapping with user multiplier and clamping

```
value = clamp( (−headAngle − offset) × multiplier , 0 … 99 )
```

- `offset` is the calibrated "zero" (neutral head position).
- `multiplier` (slider, 0–20) tunes sensitivity for each user / mounting.
- Clamping to `0–99` keeps the compact 2‑digit `iNN` wire format.

> **Patented method.** Generating the pedal signal from these **two presets —
> the angular offset (dead‑zone) and the multiplier**, which together fix a secondary
> **response speed** — is the project's patented technique (JP **特許第6726319号 / 第7004771号**).
> If you reuse it, see the licensing note in the publishing checklist.

## 4. Fire‑and‑forget BLE writes (`.withoutResponse`)

```swift
peripheral.writeValue(sendData, for: characteristic, type: .withoutResponse)
```

No per‑write acknowledgement round‑trip → minimal latency, which matters for a
real‑time pedal. This is only safe because the app already rate‑limits itself
(see #1); the two decisions are designed together.

## 5. Name‑filtered discovery + multi‑channel

The central connects **only** to peripherals advertising a known name
(`bFaaaPSwitch_1…4`) that matches the selected channel, so it never mis‑connects
to unrelated BLE devices nearby (verified on‑device: ResMed/Yamaha/etc. are
ignored). Up to **4 channels** let several devices/users coexist; a channel is
renamed by sending a single byte `W`/`X`/`Y`/`Z`.

## 6. On‑type / Off‑type behavior switch (`n` / `f`)

The device supports two pedal logics (sustain‑on‑tilt vs. sustain‑off‑tilt),
toggled from the app by sending `n` or `f`, to suit different pianos/use cases.

## 7. Screen always‑on during play

```swift
UIApplication.shared.isIdleTimerDisabled = true
```

For a foot‑free assistive instrument the display and camera must never sleep
mid‑performance; the flag is set on launch and on scene activation, and cleared
when backgrounded.

## 8. Simple UI with hidden setup gestures

The target users benefit from a minimal interface, so advanced actions hide
behind gestures — e.g. a **5‑tap** gesture jumps straight to play
(`.onTapGesture(count: 5)`), keeping the normal screen uncluttered.

## 9. Persisted calibration & channel

The selected channel, device name, and on/off‑type are stored in `UserDefaults`
so the setup survives app restarts.

## 10. Robust auto‑reconnect

On disconnect the central immediately resumes scanning
(`scanForPeripherals()`), so a brief BLE drop during a performance recovers
without user action.

## 11. Clear engage feedback (white → red)

The play screen is **white at rest and turns red the moment the head passes the
threshold** (pedal engaged), giving the player immediate, glanceable
confirmation; head up → back to white. This is the **same app for both Pro and
Switch** — only the device on the other end of the BLE link differs (a motor for
Pro, an electronic switch for Switch).

---

### If you change one thing, read this first

Items **#1 and #4 are a pair**: the fire‑and‑forget writes are only safe
because the app paces itself. If you lower the timer interval or remove the
throttle, restore an acknowledgement/backpressure mechanism or you will
reintroduce the communication bugs that motivated the 5 ms → 100 ms change.

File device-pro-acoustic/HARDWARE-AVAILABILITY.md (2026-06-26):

# Hardware availability & alternatives

> English first; 日本語・ドイツ語版は後日 `i18n/` 配下に追加予定。
>
> Some parts used in the original design are **end‑of‑life (EOL)** or hard to
> source. This page records what changed and gives **concrete, currently‑available
> alternatives** plus **tips for adapting the firmware**. The "tips" are the
> maintainers' engineering opinion — verify against your exact parts.
> Always re‑check vendor stock; availability changes over time.

## Summary

| Component (original, per BOM) | Status | Suggested replacement | Code change |
|---|---|---|---|
| **IQ‑FORTIQ‑M42BLS‑100** (IQ motor, 100 W) — **current reference (v039B)** | **EOL** — firmware notes IQ supply stopped | **Chosen path (maker, 2026‑06‑26): a closed‑loop NEMA17** — either **MKS SERVO42C/D + a NEMA17**, or a **closed‑loop stepper with a built‑in NEMA17‑class driver** (reads load over UART/CAN). | Moderate (STEP/DIR + serial position; firmware to be drafted) |
| **nRF52840 BLE board** — Pro uses **Akizuki `AE-NRF52840` (g117484)** ✅ (confirmed: cheaper, same BLE module, same board ID); **Adafruit Feather nRF52840 (4062)** is a compatible alternative. *Not* ItsyBitsy (that's the Switch's DotStar LED variant). | Current | any nRF52840 + Adafruit nRF52 BSP | Minimal (same Bluefruit API; Pro firmware has no LED routine) |
| **Raspberry Pi Pico** main board | Current | **Pico** / **Pico 2 (RP2350)** | None (mind ADC pins) |
| **HX711** (air‑pressure sensor) | Current/common | Any HX711 breakout | None |
| **n‑MOSFET 2SK4017** (pump drive) | Common | any logic‑level n‑MOSFET | None |
| **AC100→DC24V** PSU | Generic | any 24 V switching PSU | None |

---

## 1. Drive motor — IQ / Fortiq → closed‑loop stepper

**What happened.** The **current reference** Pro device (firmware **v039B**) uses
the **IQ‑FORTIQ‑M42BLS‑100** (IQ Motion Control, 100 W; ≈¥33,000 on Crowd Supply).
The project's own firmware notes the **IQ motor supply stopped**
(`IQモーターの供給停止…`); the **next** version is being rewritten for a
**closed‑loop stepping motor** (which exposes a **DRV8825‑compatible** STEP/DIR
interface). **Decision (device co‑author, 2026‑06‑26): force‑feedback approach A — a
closed‑loop driver.** The maker is choosing between **MKS SERVO42C/D + a NEMA17** and a
**closed‑loop stepping motor with a built‑in NEMA17‑class driver**; both report load /
following‑error over **UART/CAN**, which restores the IQ‑style "press until the reaction force
rises" calibration. The **buildable firmware for this configuration is to be drafted (AI‑assisted)
and bench‑tested**; the CAD is still being added to / swapped out. Early plain‑stepper tests used a
stock **DRV8825** module (see the
`DRV8825_TEST` / `updown_test_naru` design notes) — but **DRV8825 is an old,
standard module, not the new motor itself**, and the stepper sketch (`v052B`) is
still early development. IQ Motion Control now operates
as **Vertiq**; the small IQ modules are no longer easy to obtain, while the
industrial **Fortiq** line may still exist — confirm directly with the vendor.
(An even earlier prototype used an **Oriental Motor** αSTEP‑class motor driven via
MEXE02 / parallel‑I/O — useful background if you choose that vendor's closed‑loop
steppers.)

**Recommended replacement — an integrated closed‑loop stepper:**

- **MKS SERVO42C / SERVO42D** — NEMA17 closed‑loop stepper *driver with onboard
  MCU + magnetic encoder*. Supports **STEP/DIR pulse mode** *and* **serial /
  CAN with absolute/relative position** modes, holds position under load, and is
  **open source** (CC‑BY‑SA hardware, GPL firmware). NEMA23 size: **SERVO57D**.
- Or a plain **NEMA17/23 stepper + a separate closed‑loop driver** (Leadshine,
  StepperOnline "iHSS" integrated closed‑loop steppers, etc.).
- Convert rotation to the pedal push with a **leadscrew / rack** (the original IQ
  used a `meter_per_rad` transmission; a leadscrew gives the same linear push).

**Why a closed‑loop stepper fits.** The pedal must be **pushed to a position and
held there against the spring/reaction force** — exactly what the IQ servo did
and what a *closed‑loop* (not open‑loop) stepper also does. The anchoring
(airback) + "hold position" design carries over unchanged.

**Firmware adaptation tips (our opinion):**

1. **Easiest: STEP/DIR mode.** The `v052B` `move()` already bit‑bangs STEP and
   DIR. Wire the driver's **STEP / DIR / EN** to the Pico, set the driver's
   microstep, and **resolve the pin contradiction** first (the header says
   STEP=GP14/DIR=GP15 but `move()` uses 13/14 — pick one and make code+wiring
   agree). Calibrate `mm` (steps per 1 mm) to your **leadscrew pitch ×
   microsteps**.
2. **Cleaner: serial/absolute‑position mode.** MKS SERVO accepts an absolute
   position command over UART/CAN. Map the incoming `0–99` to an absolute target
   and send one command per update — this **restores the IQ‑style "go to
   position and hold"** model (closer to the old code's
   `trajectory_angular_displacement`) and lets you read encoder position/load
   back for the auto‑calibration.
3. **Lower‑limit by force still works.** Closed‑loop drivers report **load /
   power**, so the "drive down until reaction force rises → set `down_pos`"
   calibration can read load over serial. **Threshold on _power_, not current**
   (per the device co‑author): current changes with the supply voltage, whereas
   power stays consistent, so a commercial power supply can be used without
   re‑tuning. On the **IQ version the power is read by command from the IQ motor**;
   for a stepper successor the **power‑measurement method is not yet decided**.
   **Threshold value (v039B):** the pressing power is **piano‑dependent**, set by a
   **DIP switch** = **base 20 W + DIP (1 W steps) → 20–35 W** (20 W alone proved
   too weak; too strong makes the rod slip). A **50 mm travel cap** prevents the
   push‑rod from being driven out; the DIP switch also sets the lift above the
   hard stop (**5–20 mm**).
4. **Add an enable/limit safety.** Use the driver's stall/overcurrent and,
   ideally, a hardware limit so a mis‑set threshold can't over‑drive the rod.

Links: <https://github.com/makerbase-mks/MKS-SERVO42A> ·
MKS SERVO42D manual <https://manuals.plus/ae/1005005593922187> ·
IQ/Vertiq docs <https://iqmotion.readthedocs.io/> ·
Fortiq 42 <https://iqmotion.readthedocs.io/en/latest/modules/fortiq_42XX.html>

---

## 2. BLE board — nRF52 (Adafruit Bluefruit)

For the **Pro**, the board is the **Akizuki `AE-NRF52840`** (confirmed by Taguchi,
2026‑06‑24); the Pro firmware has no LED routine. The **Adafruit ItsyBitsy
nRF52840 Express** with its **onboard DotStar** RGB LED (`DATAPIN 8 / CLOCKPIN 6`)
is the **Switch** line's board (see
[`../device-switch-electronic/firmware/`](../device-switch-electronic/firmware/)).
The BLE sketch uses the **Adafruit Bluefruit** stack (`#include <bluefruit.h>`), so
it runs on any **Adafruit nRF52840** board with only board‑selection changes — pick
the ItsyBitsy if you want an onboard DotStar status colour.

- **Adafruit Feather nRF52840 Express** — current, well‑documented, easy to wire.
  <https://www.adafruit.com/product/4062>
- **Seeed Studio XIAO nRF52840** — very small (21 × 17.5 mm), low power; great if
  space is tight. Runs the Adafruit nRF52 core / Bluefruit.
- Also: **Adafruit ItsyBitsy nRF52840 Express** <https://www.adafruit.com/product/4481>.

**Firmware adaptation tips:** install the **Adafruit nRF52 BSP** in the Arduino
IDE, pick the board, and rebuild — the Bluefruit API (`BLEUart`, `setName`,
advertising, callbacks) is unchanged. **Re‑check pin numbers**: the sketch toggles
`GP13` for the direct on/off output and writes the UART on `Serial1` — map those
to your board's actual pin labels (the XIAO's pin map differs from the Feather's).

---

## 3. Main board — Raspberry Pi Pico / Pico 2

The Pico (RP2040) is current, and **Pico 2 (RP2350)** is the newer generation;
both are supported by the `arduino-pico` core. Little to change.

**Tip — watch the ADC pins (resolved by the schematic).** Some firmware reads
`A3`; on a stock Pico **`A3` (GP29) is the on‑board VSYS voltage divider**, not a
free analog input. The **circuit schematic** (see
[`hardware/schematic/`](hardware/schematic/)) puts the slider potentiometer on
**`ADC0` / GP26**, which is correct — so **align the firmware to the schematic
(slider on ADC0/GP26)** rather than `A3`. When consolidating the analog inputs
(motor power/load, air pressure, slider), also clean up the sketch's reuse of `A0`
for two purposes.

---

## 4. Sensors, MOSFET, air pump

- **HX711 + load cell** is current and cheap. Note the firmware currently mixes
  "HX711" with an analog current read — decide which is the real force/pressure
  sensor and wire accordingly (HX711 is a 2‑wire DOUT/SCK device, **not** I²C).
- **MOSFET + air pump** for the airback are generic; pick a logic‑level MOSFET
  rated for the pump current and a 12 V (typ.) diaphragm pump. Add a flyback
  diode across the pump.

---

## Sources

- IQ Motion Control / Vertiq docs — <https://iqmotion.readthedocs.io/>
- IQ Fortiq 42 module — <https://iqmotion.readthedocs.io/en/latest/modules/fortiq_42XX.html>
- IQ Motor Module (Crowd Supply, original) — <https://www.crowdsupply.com/iq-motion-control/iq-motor-module>
- MKS SERVO42 (open source) — <https://github.com/makerbase-mks/MKS-SERVO42A>
- MKS SERVO42D manual — <https://manuals.plus/ae/1005005593922187>
- Adafruit Feather nRF52840 Express — <https://www.adafruit.com/product/4062>
- Adafruit ItsyBitsy nRF52840 Express — <https://www.adafruit.com/product/4481>
- Raspberry Pi Pico series — <https://www.raspberrypi.com/products/raspberry-pi-pico/>

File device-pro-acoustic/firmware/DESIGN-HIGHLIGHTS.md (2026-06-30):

# Firmware — design highlights & flowcharts

> English first; 日本語・ドイツ語版は後日 `i18n/` 配下に追加予定。
> Firmware by **Hiroyuki Narusawa**.

Control firmware reads better as **flowcharts** than as prose, so the behaviour
of each board is drawn below. Diagrams use Mermaid (rendered by GitHub).

---

## Is there asynchronous processing? — Yes, on the BLE board only

This is the key architectural fact.

| Board | Model | Why |
|---|---|-----|
| **BLE board** (nRF52 / Bluefruit) | **Asynchronous / event‑driven** | The Nordic **SoftDevice** runs the radio in the background (interrupt context). `connect_callback` / `disconnect_callback` fire **asynchronously** on connection changes; incoming bytes are buffered asynchronously; `restartOnDisconnect(true)` re‑advertises by itself. `loop()` merely **polls** that buffer. |
| **Main board** (RP2040 / Pico) | **Synchronous / blocking** | A single‑threaded polling `loop()`. `move()` busy‑waits with `delayMicroseconds()`, calibration uses blocking `while` loops, and `setup()` blocks on the air‑jack and limit search. No interrupts, callbacks, or RTOS. |

**Why the split is deliberate.** BLE timing is hard real‑time, so it is offloaded
to the SoftDevice (async). Motor motion wants deterministic, ordered, blocking
steps, so the main board stays simple and synchronous. The **wired UART
decouples the two timing domains** (async radio ↔ sync motion) — the same idea
the iOS app uses to decouple the AR frame rate from the BLE send rate.

---

## BLE board (nRF52)

### Boot

```mermaid
flowchart TD
    A([power on]) --> B["Serial1.begin 115200"]
    B --> C["Bluefruit.begin, TxPower -4"]
    C --> D["InternalFS.begin"]
    D --> E{"/W.txt exists?"}
    E -->|yes| F["read index i; setName bFaaaPSwitch_(i+1)"]
    E -->|no| G["create /W.txt='0'; setName bFaaaPSwitch_1"]
    F --> H["register connect/disconnect callbacks"]
    G --> H
    H --> I["begin DFU, DIS, UART, Battery services"]
    I --> J["startAdv: advertise, restartOnDisconnect=true"]
    J --> K([enter loop])
```

### Main loop — command dispatch (polls the async RX buffer)

```mermaid
flowchart TD
    L([loop]) --> M{"bleuart.available?"}
    M -->|no| L
    M -->|yes| N["ch = bleuart.read"]
    N --> O{"ch ="}
    O -->|"N"| P["GP13 on  (polarity by rr)"]
    O -->|"F"| Q["GP13 off (polarity by rr)"]
    O -->|"i"| R["read 2 ASCII digits, atoi to byte 0..99, Serial1.write to main board"]
    O -->|"n"| S["rr=1 (on-mode)"]
    O -->|"f"| T["rr=0 (off-mode)"]
    O -->|"W/X/Y/Z"| U["write channel index 0..3 to /W.txt"]
    P --> M
    Q --> M
    R --> M
    S --> M
    T --> M
    U --> M
```

### Asynchronous events (run outside `loop`)

```mermaid
flowchart LR
    SD[["nRF52 SoftDevice (BLE stack)"]] -. async .-> CC["connect_callback"]
    SD -. async .-> DC["disconnect_callback then auto re-advertise"]
    SD -. async .-> RX["fills BLEUart RX buffer"]
```

---

## Main board (Pico)

### Boot sequence (three mechanisms, in order)

```mermaid
flowchart TD
    A([power on]) --> B["delay 5s; init serials & pins"]
    B --> C["1) auto_air_jack(): air pump ON (GP12 MOSFET)"]
    C --> D{"air pressure >= hi_p ? (ADC)"}
    D -->|"no, elapsed < 30s"| C
    D -->|"timeout 30s and still < low_p"| E["error beep (GP13), halt"]
    D -->|"yes -> device anchored"| F["2) auto_set(): step the drive toward the LOWER end"]
    F --> G{"motor power (= reaction force / torque) >= threshold?"}
    G -->|no| F
    G -->|"yes -> hard stop hit"| H["back off a little; LOWER limit = down_pos"]
    H --> I([enter loop])
    I --> J["3) every loop: UPPER limit up_pos set LIVE from the slider (ADC A3)"]
```

### Main loop — position the pedal

```mermaid
flowchart TD
    L([loop]) --> M{"Serial1.available?"}
    M -->|no| L
    M -->|yes| N["byte = read (0..99)"]
    N --> O["pos = map byte: 0..99 to up_pos..down_pos"]
    O --> P{"abs(byte - last) > 2 ?"}
    P -->|no| L
    P -->|yes| Q["move motor to pos"]
    Q --> R["delay ~100 ms; last = byte"]
    R --> S["read travel-limit pot; adjust up_pos"]
    S --> L
```

---

## Self‑calibration & anchoring (boot mechanisms in detail)

At power‑up the device makes itself **anchored and self‑referenced** before it
will respond to the app. Three mechanisms run, in this order:

**1) Air‑jack anchoring — `auto_air_jack()`.**
Before any pedal force is applied, the firmware runs the **air pump**
(GP12 → MOSFET) to inflate the **airback** bag under a neighbouring pedal. It
keeps pumping until the measured air pressure reaches `hi_p` (read on the ADC),
with a **30‑second timeout**. If pressure still cannot reach `low_p`, it sounds a
continuous **error beep** (GP13) and halts — i.e. it refuses to operate unless
the unit is firmly fixed. This guarantees the device cannot shift when the motor
later pushes the sustain pedal.

**2) Lower end (下端) — automatic, by reaction force — `auto_set()`.**
The drive is stepped toward the pedal until it physically bottoms out. The
firmware watches the **motor _power_**, which is proportional to **torque /
reaction force**: when the push‑rod meets the hard stop the power rises past a
threshold (`mot_cu_down`). That contact point (after a small back‑off) becomes
the **lower limit `down_pos`** — the deepest the pedal is pressed. A safety cap
(50 mm) stops the rod being driven out.

> **Why power, not current (per device co‑author):** the threshold is on **electrical
> power**, not current, because the **current changes with the input voltage**
> whereas **power stays consistent across supply voltages** — so a commercial,
> off‑the‑shelf power supply can be used without re‑tuning. On the **IQ (v039B)**
> version the power is **read by command from the IQ motor** (its telemetry). For
> the planned **stepper successor**, the power‑measurement method is **not yet
> decided** (no IQ telemetry).
>
> **Threshold value (v039B):** piano‑dependent (reaction force differs); set by a
> **DIP switch** = **base 20 W + DIP, 1 W steps → 20–35 W** (20 W alone was too
> weak; too strong makes the rod slip). The DIP switch also sets the lift above the
> hard stop (5–20 mm), and a **50 mm travel cap** stops the rod being driven out.

**3) Upper end (上端) — manual, by slider — `offset_AD_read()`.**
The top of travel — where the pedal rests / releases — is **not** auto‑detected.
The user sets it with the **slider on the hand controller**, which the firmware
reads on **ADC A3** every loop and converts to `up_pos = orig_pos + mm × slider`.
Moving the slider changes the resting height **live**, so the operator dials in
exactly how far the pedal returns up and where the drive stops.

Together `down_pos` (auto, by force) and `up_pos` (manual, by slider) define the
range; incoming `0–99` values from the app are mapped linearly between them
(`mapf(byte, 0, 99, up_pos, down_pos)`).

> WIP note: in the stepper sketch the thresholds (`low_p`, `hi_p`, `mot_cu_up`,
> `mot_cu_down`) are not yet given real values, and `auto_set()` additionally
> probes an upper hard stop to establish the reference frame; the *operational*
> upper limit is the slider, as above.

## Key design points

1. **Channel name persistence (LittleFS).** The advertised name
   `bFaaaPSwitch_1…4` is stored as a one‑char index in `/W.txt` and applied at
   boot via `setName`. `W/X/Y/Z` rewrite the file; the change takes effect on the
   **next reboot** (the `deep_sleep`/reset call is commented out).
2. **The BLE board is dual‑role.** `GP13` gives a direct on/off output (enough
   for an electric‑piano "Switch"), while `iNN` is forwarded to the main board
   for proportional motor control ("Pro"). One firmware, two product uses.
3. **ASCII → binary compaction.** `iNN` (3 bytes) becomes **one byte (0–99)** on
   the UART link, minimizing wired traffic between the boards.
4. **Dead‑band on the main board.** A new position is acted on only when
   `abs(byte − last) > 2`. This mirrors the iOS‑side hysteresis and ignores
   small head jitter, so the motor isn't re‑commanded constantly.
5. **Lower limit auto (by force), upper limit manual (by slider).** The lower
   end is found automatically — no limit switch — from the **rise in motor
   _power_ (reaction force/torque)** at the hard stop; **power is used rather than
   current because current changes with the supply voltage while power does not**
   (so a commercial power supply needs no re‑tuning). The upper end is set
   **live by the hand‑controller slider**. See *Self‑calibration & anchoring*
   above. (The force/power thresholds are piano‑dependent and still need real
   values.)
6. **IQ trajectory control — the reference version (v039B).** One command sets
   target displacement + duration; the IQ servo then drives there and **holds
   against the pedal's reaction force**. This IQ version is the **current
   reference design**. Because the IQ motor was discontinued, the **next** version
   will use a closed‑loop **stepping motor** (which accepts a DRV8825‑compatible
   STEP/DIR interface); that sketch (v052B) is still early development (see
   *Status & caveats*).
7. **Air‑jack anchoring at boot** with pressure feedback, a 30 s timeout, and an
   audible error if pressure can't be reached — so the unit is fixed before any
   pedal force is applied.
8. **On/Off‑mode polarity (`rr`).** `n`/`f` flip whether a tilt means
   "sustain on" or "sustain off", inverting the `GP13` output sense.

---

## Status & caveats

- The **stepper sketch `v052B` is a development snapshot**: it is missing
  `#include`s, has undefined threshold constants, an unclosed `setup()` with a
  leftover test loop, a `Serial1`/`Serial2` mismatch for BLE, and STEP/DIR pin
  numbers that disagree between the header and `move()`. Treat it as the
  *intended design*, not buildable firmware yet.
- A consolidated list of what must be resolved to make the device reproducible
  (driver/board part numbers, wiring, power, sensor choice, build‑ready
  firmware) is tracked in the project notes (hardware reproducibility gap
  analysis).

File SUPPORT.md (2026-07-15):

# 💛 Support bFaaaP

> 🌐 **English** · [日本語](i18n/ja/SUPPORT.md) · [Deutsch](i18n/de/SUPPORT.md)

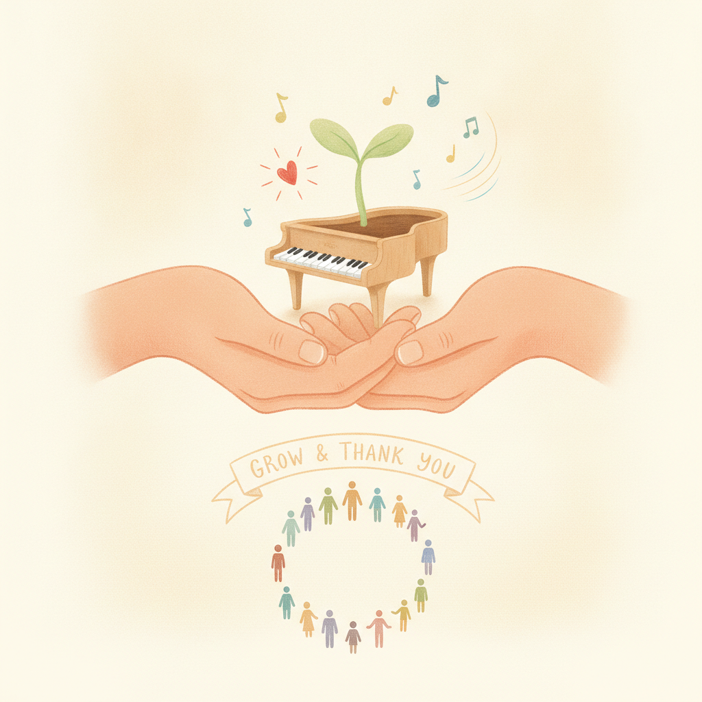
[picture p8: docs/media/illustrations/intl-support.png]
Hands holding a piano with a growing sprout, surrounded by a community


bFaaaP is an **open‑source, inclusive** project. The devices aren't sold — everything is
published so anyone can build and improve them, and pianists who cannot use their feet can
play. Your support keeps the project free and growing. 🙏

## 🙋 Need help building? (Community Support)
Ask in **[GitHub Discussions (Q&A)](https://github.com/bfaaap/bfaaap_opensource/discussions)**.
The **bFaaaP community and team answer using this repository's own open materials** — answers
are checked by real people for safety/accuracy, so they're public and **not instant** (a reply
can take a few days). Ask in **any language**; we reply in the same language, and useful answers
**improve these docs**. Full flow: [`docs/ai-support.md`](docs/ai-support.md).

## Where your support goes
- Developing & maintaining the iOS app, firmware, and hardware designs
- **Community Support** (the GitHub Discussions Q&A where the community and team answer build questions — see [`docs/ai-support.md`](docs/ai-support.md))
- Parts & loaner devices for makers and users who need them
- Concerts, lessons, and demonstrations for people with disabilities

## Ways to give

| Method | One‑time | Monthly | Notes |
|---|:---:|:---:|---|
| **PayPal** | ✅ | ✅ | PayPal balance, **credit/debit card, or Apple Pay** (on PayPal's checkout) |
| **Stripe** | 🔜 | 🔜 | Card, **Apple Pay / Google Pay** — *Payment Link coming soon* |
| **GitHub Sponsors** | — | — | Use the **Sponsor** button on this repo |

### PayPal — one‑time
- **[¥1,000](https://paypal.me/ShishidoAssociates1/1000)** · **[¥3,000](https://paypal.me/ShishidoAssociates1/3000)** · **[¥5,000](https://paypal.me/ShishidoAssociates1/5000)** · **[any amount](https://paypal.me/ShishidoAssociates1)**

### PayPal — monthly
Monthly supporter plans (¥500 / ¥1,000 / ¥3,000) are offered through PayPal Subscriptions.
*(Subscription buttons need JavaScript, so they live on the bFaaaP website rather than here;
this page links to one‑time giving, which works anywhere.)*

### Stripe — coming soon
A Stripe **Payment Link / Buy Button** (card, Apple Pay, Google Pay; one‑time & monthly)
will be added here, billed via **Shishido & Associates**. *(Placeholder — link pending.)*

---
> bFaaaP is run by **Shishido & Associates**. Contributions are *support for an open
> project*, **not** tax‑deductible charitable donations. Thank you for helping make music
> accessible. **Build questions → [GitHub Discussions](https://github.com/bfaaap/bfaaap_opensource/discussions)** (Community Support). Other contact: <shishid@saaipf.com>

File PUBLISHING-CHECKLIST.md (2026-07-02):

# Publishing checklist — review BEFORE making this repository public

This folder is staged for open-source release. Work through every item below
before pushing to a public GitHub repository.

## 1. Secrets & credentials (CRITICAL)

- [ ] **App Store Connect API key** — the file `temp_info/AuthKey_<KeyID>.p8`
      and the Key ID / Issuer ID noted in the parent `CLAUDE.md` are **secrets**.
      They live OUTSIDE this folder; make sure they are never copied in.
      **Revoke** the key in App Store Connect once upload work is finished
      (Users and Access → Integrations).
- [ ] Confirm no `*.p8`, `*.mobileprovision`, `*.p12`, `*.cer`, provisioning
      profiles, or signing certificates are inside `github_opensource/`.
      (`.gitignore` blocks these; the iOS source in `ios-app/src/` was imported
      with signing data removed — verify.)
- [ ] The internal `CLAUDE.md`, `temp_info/`, and `*.zip` archives in the parent
      directory are **not** part of this folder and must not be published.

## 2. Personal information (PII)

- [ ] `device-pro-acoustic/assembly/` — the original `readme.pdf` may contain
      names/addresses/contact details. Review and redact before including.
- [ ] `device-pro-acoustic/hardware/enclosure-labels/` — the product label
      (`*.odt`) may contain personal/branding info. Not yet copied in; review first.
- [ ] Author attribution: per decision, author names in source/CAD headers are
      **kept** as credit. (`ios-app/src/` keeps `Created by …` headers.)
- [ ] `ios-app/src/` was sanitized: `DEVELOPMENT_TEAM` blanked, bundle ID set to
      placeholder `com.example.bfaaap`, `xcuserdata`/secrets removed — verify.
- [ ] `docs/members/` uses public caricatures from bfaaap.com; **personal contact
      details** (phone/email from the source pages) were **omitted** — confirm none
      slipped in. Get member consent for including their portrait/bio.
  - [x] **Illustration copyright (artist = Saki Shiokawa / 塩川紗季)** — the original
        hand-drawn member portraits (`docs/members/*`) + avatars (`docs/media/avatars/*`)
        are her copyrighted works. **Consent OBTAINED 2026-07-02** (LINE; kept private in
        `member_consent_info/塩川紗季_著作権_consent.png` + CONSENT_LOG). Credit "© Saki
        Shiokawa (塩川紗季) / bFaaaP"; only AI scene/hero/ai-avatar keep "…style".
- [ ] `ios-app/app-store/` & `docs/media/` use the project's own public assets
      (App Store screenshots, concert thumbnails, poster). Confirm reuse is intended.

## 3. Third-party licensing

- [ ] `device-pro-acoustic/motor/` — IQ / Fortiq datasheets are **vendor
      copyright**, intentionally **not redistributed** (referenced only). Keep it so.
- [x] **ROHM `RU1J002YN` MOSFET datasheet** (Switch) — vendor copyright (© ROHM).
      Narusawa shared the PDF privately (2026-06-24); it is **kept out of the repo**
      and **referenced by link only** (docs link to the official ROHM product page).
- [ ] `device-pro-acoustic/firmware/libraries/iq-module-communication-arduino/` —
      keep its original `LICENSE`/attribution intact; verify redistribution is allowed.
- [x] `device-pro-acoustic/hardware/schematic/` — the circuit schematic + block /
      power diagrams are by **Taguchi** (github.com/reodon), imported from
      `reodon/copy_bfaaap_pro`, which had **no license file**. **Taguchi consented
      (2026-06-18)** and agreed to waive rights to the maximum extent → released
      under the hardware layer (**CERN-OHL-W-2.0**). **KiCad source delivered by
      Taguchi (2026-06-24)** and **imported** to `hardware/schematic/kicad/`
      (`.kicad_sch` authoritative; `.kicad_pcb` empty stub) — scanned clean of
      absolute paths / PII before committing.
- [x] `device-pro-acoustic/hardware/cad/from-discord-2025/` and
      `3d-print/from-discord-2025/` — CAD/STL shared by **H. Narusawa** in the team
      **Discord**. **Narusawa consented (2026-06-14)** to co-authorship, GitHub name
      credit, and including this CAD. *(A project license still needs to be chosen
      before publishing — see §4.)*
- [x] `device-pro-acoustic/hardware/photos/` — build photos (airback + drive unit)
      by **Taguchi** from the Discord. **Taguchi (photographer) consented
      (2026-06-18)** (no people/PII shown).
- [x] `device-pro-acoustic/hardware/PARTS-REFERENCE.md` + `hardware/reference/` —
      parts **data** adapted from `TomoShishido/bfaaapteam` (`docs/hardware.md`, by
      consented co-authors Taguchi & Narusawa). `DISCORD-FINDINGS.md` summarizes a
      **private Discord**; build photos/videos are **kept out** of the repo.
      ✅ **Image provenance resolved (2026-06-24):** Taguchi flagged that the two
      images in the legacy `docs/hardware.md` (`rpi_pico/pinout.svg`,
      `fortiq42/electrical-interface.png`) were brought in from elsewhere with
      **unknown license**. Both were **removed** and **replaced with original
      bFaaaP-project matplotlib drawings** (`pico_pinout_bfaaap.png`,
      `fortiq42_interface_bfaaap.png`, CC BY 4.0) plus links to the official
      Raspberry Pi / Vertiq sources. No third-party images of uncertain license remain.
      ✅ **Likely original sources confirmed by Taguchi (2026-06-25):** the Pico image
      most likely came from the **Raspberry Pi Pico documentation / datasheet**
      (RP2040-based board) and the motor image from the **Fortiq BLS42 datasheet**
      (`fortiq_datasheet.pdf`) — i.e. **vendor copyright** (© Raspberry Pi Ltd / © IQ
      Motion Control). This confirms removing-and-redrawing was the correct call; we
      redistribute no vendor image and only **link** to those official sources.

## 4. Project license & patents

- [x] Project `LICENSE` **adopted** (2026-06-18): software → **Apache-2.0** (explicit
      patent grant), hardware → **CERN-OHL-W-2.0**, documentation → **CC-BY-4.0**.
      Full, verbatim texts added under [`LICENSES/`](LICENSES/) (Apache-2.0,
      CERN-OHL-W-2.0, CC-BY-4.0); top-level `LICENSE` records the layer split,
      patents, contributor consent, and third-party components.
- [ ] **Patent decision (important).** The control method is patented in Japan —
      **JP 6726319 B2** (Auxiliary pedal system) and **JP 7004771 B2** (Device
      controller); priority‑basis PCT **WO 2019/176164**. Policy (in README/LICENSE):
      licensing depends on the embodiment, but **public/open‑purpose uses can be
      licensed free of charge**; in particular, **products/services that enable
      inclusive social participation for people with disabilities — even paid /
      commercial ones — are licensed free of charge as a matter of policy.**
      **Contact T. Shishido.** For the software license, prefer one **with an
      explicit patent grant (Apache‑2.0)**; MIT has none.

## 5. Content to populate / decide

- [x] iOS source vendored into `ios-app/src/` (sanitized, buildable with your own team).
- [ ] Fill `device-pro-acoustic/assembly/` with the real build guide + sourced BOM.
- [ ] Add airback details (dimensions, pump/controller schematic, photos) to
      `device-pro-acoustic/hardware/airback/`.
- [ ] Add firmware wiring/pin docs and recommended 3D‑print settings.
- [ ] Confirm `hardware/3d-print/` meshes match the latest CAD revision.
- [ ] Populate `device-switch-electronic/` when that line is ready.

## 6. Localization

- [ ] Docs are **English‑first**. After approval, create Japanese and German
      versions in separate `i18n/ja/` and `i18n/de/` subfolders.

## 7. Final

- [x] **Git history purge — DONE (2026-06-24).** The private peer-review / TACCESS files (an arXiv-version split kept
      separate) were stripped from **all** history with
      `git-filter-repo`, `main` was **force-pushed**, and the obsolete
      `feature/docs-overhaul` + `feature/i18n-reference-docs` remote branches (which
      still carried the old history) were **deleted**. Verified: gone from
      `origin/main` history, 0 sensitive objects, working content unchanged. A
      private backup bundle exists outside the repo — **delete it before going
      public**. For absolute certainty, ask **GitHub Support to expire unreachable
      objects** before flipping the repo to public (do NOT delete/recreate the repo —
      it holds the AI-support Discussions).
- [ ] Working tree is on the existing private remote; review `git status` against
      `.gitignore`, then change repository visibility to **public** (final step).
- [ ] **Payment smoke-test — AFTER going public.** Once the repo is public, run a small **real**
      payment through each LIVE method to verify the end-to-end flow, confirm it lands in the
      account, then refund/cancel:
      - **PayPal (LIVE now):** send e.g. **¥1,000** via the PayPal.me link in `SUPPORT.md`
        (`paypal.me/ShishidoAssociates1`); confirm receipt in the **Shishido & Associates** PayPal
        account and that **card / Apple Pay** appear on PayPal's checkout. Optionally start a **¥500
        monthly** plan on the bFaaaP website and cancel it immediately. Public values (PayPal.me URL,
        Plan IDs `P-…`) live in `saaipf_business/paypal_manage/credentials/bfaaap_support.md`.
      - **Stripe (NOT live yet):** Stripe for bFaaaP support is **planning-stage** and gated to
        **saaipf.com go-live (publication order ③, after bfaaap is public)** — keep `SUPPORT.md` at
        "Stripe — coming soon" until then. When its **Payment Link** is added, repeat this small-
        amount test (card + Apple Pay / Google Pay) and refund. See `saaipf_business/stripe_manage/`.

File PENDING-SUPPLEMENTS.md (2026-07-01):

# Pending supplements — content to add before publication

> Working tracker (started 2026-06-30, Plan §21 in the private `CLAUDE.md`).
> Items here are **deliberately not finalized yet** because they depend on
> information still in flight (team review, member messages, external partners).
> Resolve every item before flipping the repository public.
> This file is internal working state; remove or fold into `PUBLISHING-CHECKLIST.md`
> at release.

## A. Device finalization (gates "device creation complete")

- [ ] **Pro — New Generation / successor motor (Tanaka draft + Narusawa feedback).**
      Tanaka is deepening the "New Generation Model" draft and will share via LINE;
      Narusawa's impressions on it close out the substantive device-build work.
      Until then, keep the current draft framing ("original = IQ/Fortiq M42BLS, **EOL**;
      successor = closed-loop NEMA-17 class, **under evaluation**"). Do **not** hard-code
      final part numbers, pinout, or firmware values for the successor across README /
      build/pro / device-pro-acoustic / arXiv / TACCESS.
      - On finalize: update README BOM, `docs/build/pro.md`, `device-pro-acoustic/**`,
        `HARDWARE-AVAILABILITY.md`, motor firmware draft, and both papers consistently.
- [ ] **Pro — airback / air-pump drive (electric GP12 → 2SK4017 vs WINBAG manual) and
      HX711 retain/remove** — depends on the successor decision above. Keep current text;
      do not delete HX711/2SK4017/24V references until confirmed.

## B. People / messages / partners (consent-gated)

- [ ] **Yamaguchi banner permission** — to be granted at tomorrow's lesson. Banner
      illustrations are staged locally (`docs/media/illustrations/studio*-banner-*.png`).
      Do not publish the banner publicly until permission is confirmed.
- [ ] **New member additions** (e.g. Nagasawa Keiko portrait/avatar staged) — confirm
      consent + display-name rules before publishing in members/story.
- [ ] **External partner message** — Tokyo Women's Choral Society (currently being
      approached). Add their message / acknowledgement once received and approved.
- [ ] **Additional member messages** (`member_messages/`, private staging) — weave into
      members / voices / story / support pages with consent and display-name rules.
- [ ] **Voices** — overview `docs/voices.md` (EN, 9 members incl. Tanaka, Shishido first) + subfolder
      **`docs/voices/<slug>.md`** = each member's **verbatim original (JA) + mirror translation (EN)**
      (ported from `member_messages/`, internal frontmatter stripped). Overview links to each full file.
      TODO: (a) add `i18n/ja/docs/voices.md` + `i18n/de/docs/voices.md` overview mirrors in P3 (the
      per-member full files are already bilingual, so they can be shared); (b) **append more voices as
      they arrive** (one overview section + one `voices/<slug>.md` per member); (c) `voices/shishido.md`
      **withholds the non-member name "Yoshida"** pending consent — restore only if he consents.
- [ ] **P4 member-bio check** — when updating bfaaap.com / saaipf.com, confirm Fati is shown as
      **holding a Ph.D.** (not "doctoral course") and Tokushige as **Patent Engineer** (not Patent
      Attorney). (2026-06-30 grep found neither bio present on those sites; re-verify in P4.)
- [ ] **P4 APEE-table check** — when updating bfaaap.com / saaipf.com, if the APEE participant table or
      offset/multiplier ranges are shown, use the corrected values (mult: I 10–40, II 20–30, III 8–50;
      offset I 5–19°/II 5°/III 3–10°; span offset 3–19°/mult 8–50), not the old I 15–40 / III 30–50.
      (2026-07-01 grep: not currently on either site; instruction recorded in both sites' CLAUDE.md.)
- [x] **Non-member name "Yoshida"** appears in Shishido's origin story draft — **RESOLVED
      2026-07-01: consent obtained** (LINE, `member_consent_info/吉田さん_consent.png`; "全然問題ない
      ですし、入れていただき光栄です"). Surname-only **"Yoshida"** restored in
      `docs/voices/shishido.md` (EN/JA/DE) and bfaaap.com `voices.ts` (en/ja/de): "the then-president"
      → "the then-president Mr. Yoshida" etc. saaipf.com has no origin-story president passage (no
      change). Logged in `member_consent_info/CONSENT_LOG.md`.

## B2. Papers (arXiv + TACCESS) — RESOLVED (flow review, 2026-07-01)

> BOM update, Future-perspectives (Narusawa), Taguchi→Acknowledgements, safe
> consistency fixes, and the author's three decisions are all DONE; both papers
> recompile clean (arXiv 27 pp / TACCESS 23 pp, 0 errors, 0 undefined refs).

- [x] **Offset/multiplier headline (3–10° / 10–50).** KEPT as-is per author — it is the
      actual movable range / a specific set of participants' choices; Table 1 carries the
      full as-used span.
- [x] **Table 1 reconciled with Table 9 (appendix, all 46 recordings).** The *row*
      multipliers were wrong, not the caption: Class I 15→**10**–40, Class III 30→**8**–50;
      Class II 20–30 and all offsets (I 5–19, II 5, III 3–10) confirmed correct. Overall
      span back to **multiplier 8–50 / offset 3–19** (caption). (Headline 10–50/3–10° kept
      per author as the recommended operating range.)
- [x] **Concert year** set to **2018–2025** (matches the latest cited event).
- [ ] *(optional, pre-existing, not addressed)* survey-table fractional counts (4.5/7.5
      = split responses?) and Eurovent year (2002 data vs 2005 cite) — author may leave.
- [ ] Separate, still open: **arXiv submission** itself (finalize license/patent-grant,
      upload LaTeX source, add arXiv ID/DOI) — see memory [[arxiv-paper-submission]].

## B3. P3 — JA/DE GitHub site (DONE 2026-07-01)

- [x] EN finalized (control-law wording → offset+multiplier→response-speed everywhere; eyes-free
      reworded; 65→50 mm; operation numbering; README successor=NEMA17 / frame 2040·2080·4040).
- [x] Propagated to existing JA/DE; full i18n control-law re-scan = 0 old framing.
- [x] Translated 6 new docs to JA + DE: voices.md, ai-team-live.md, ai-support-example-pro-motor.md,
      references/README.md, ai-support/threads/README.md, docs/README.md. Switchers live; Voices added
      to JA/DE README nav + JA/DE ai-support cross-refs.
- [x] **EN/JA/DE parity** (26 = 26 translatable docs) · **full-repo link check 0 broken (1575 links)**.
- [ ] **Remaining small P1 EN device-doc cleanups** (non-translated docs, settled, low priority):
      device-pro-acoustic/README.md drop "(planned)" for Switch; airback/README.md + hardware/README.md
      reword manual-bulb→electric-pump-is-the-built-device; firmware/DESIGN-HIGHLIGHTS.md note slider on
      ADC0/GP26 (firmware A3 = to-fix); assembly/README.md drop "(via RJ45)"; 3d-print printer/slicer
      reconcile (QIDI X-Plus4 authoritative).

## C. Payments / external services

- [x] **PayPal — LIVE.** `SUPPORT.md` (en/ja/de) already carries the production PayPal.me
      one-time links (`paypal.me/ShishidoAssociates1`); monthly subscription (¥500/1,000/3,000)
      lives on the bFaaaP website (needs JS, can't render in GitHub Markdown). Public values
      (PayPal.me URL, Plan IDs `P-…`) = `saaipf_business/paypal_manage/credentials/bfaaap_support.md`.
- [ ] **Stripe — NOT live for bFaaaP (planning-stage).** `stripe_manage/credentials/README.md`:
      Stripe-for-bFaaaP is still planning; **no Payment Link created**, and live Stripe billing is
      **gated to saaipf.com go-live (publication order ③, after bfaaap public)**. Keep `SUPPORT.md`
      at "Stripe — coming soon" until then (adding a live link now = publication-order violation).
- [x] **Publish-time payment smoke-test** added to `PUBLISHING-CHECKLIST.md §7` (small real payment
      via PayPal after going public; same for Stripe when added).
- [x] **Language policy for payment/support pages** (user 2026-07-01, revised). GitHub German
      SUPPORT page **stays German** (confirmed).
      - **Support/payment PAGE display = each in its OWN language** (bfaaap.com & GitHub: ja=日本語 /
        en=English / de=Deutsch).
      - **Checkout after a PayPal/Stripe button auto-localizes** to the buyer's browser locale, so
        **no separate links per language are needed** — one link/button per amount serves all
        languages. Separate links only per **currency** (JPY vs USD; already exists).
      - **Wording WE control** (custom button labels / Stripe Payment-Link product name+description /
        custom checkout text): **simple → each language; complex → JA site Japanese, others English.**
      - Same policy recorded in both site CLAUDE.md files (bfaaap.com / saaipf.com).

## D. Pre-public gate (from PUBLISHING-CHECKLIST §7 / CLAUDE.md §13)

- [ ] Delete `prepurge-backup.bundle` (outside repo) + ask GitHub Support to expire
      unreachable objects (do **not** delete/recreate the repo — Discussions live there).
- [ ] Final `git status` vs `.gitignore`, then flip visibility to public.

## P1 verification findings — deferred (recorded, not yet fixed)

> Items the English re-verification (Plan §21 P1) surfaced that are blocked on the
> above rather than being a settled fix. Appended as found.

<!-- (P1 fills this in) -->

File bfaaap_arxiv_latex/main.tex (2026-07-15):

% bFaaaP arXiv preprint --- full revision (2026-06-14)
% Compiles with: pdflatex -> bibtex -> pdflatex -> pdflatex  (uses refs.bib).
% Suggested arXiv categories: primary cs.HC, cross-list cs.RO (and eess.SY).
% The paper body (Introduction -> Conclusion) is shared with the ACM TACCESS
% version via draft_sections/body.tex, so both stay in sync.
\documentclass[11pt]{article}

\usepackage[margin=1in]{geometry}
\usepackage[utf8]{inputenc}
\usepackage[T1]{fontenc}
\usepackage{lmodern}
\usepackage{amsmath,amssymb}
\usepackage{graphicx}
\usepackage{booktabs}
\usepackage{array}
\usepackage{longtable}
\usepackage{xcolor}
\usepackage{fancyvrb}
\usepackage[hidelinks]{hyperref}
\usepackage{authblk}
\usepackage{caption}

% The shared body uses \Description{} (figure alt-text) for the ACM/acmart
% version; in article it is a harmless no-op.
\providecommand{\Description}[1]{}

\title{\textbf{bFaaaP: An Inclusive, Head-Angle Piano-Pedal Interaction that
Quantitatively Reproduces a Pianist's Intended Pedalling---Foot-Free, for
Acoustic and Electronic Pianos}}

\author[1,2]{Tomoyuki Shishido\thanks{Corresponding author and first author.
ORCID: \href{https://orcid.org/0000-0002-8944-2088}{0000-0002-8944-2088}
(\url{https://orcid.org/0000-0002-8944-2088}). Email:
\texttt{shishid@saaipf.com}.}}
\author[3]{Masahiro Ootaki}
\author[4]{Hiroyuki Narusawa}
\affil[1]{Shishido \& Associates, Horinouchi, Hachioji, 192-0355, Tokyo, Japan}
\affil[2]{SeemeData Labs, Inc., 2-19-2 3F Nakano, Nakano-ku, 164-0001, Tokyo, Japan}
\affil[3]{Ootaki \& Architects, Fujimi 1-19-15, Sayama, 350-1306, Saitama, Japan}
\affil[4]{Naru Science Software, Fujimi-shi, 354-0024, Saitama, Japan}

\date{Preprint --- July 2026}

\begin{document}
\maketitle

\begin{abstract}
Expressive piano performance depends on the sustain (damper) pedal, operated by
foot---excluding players who cannot readily use their feet: wheelchair users and
others with lower-limb impairments, small children, and some elderly or disabled
players. We present \textbf{bFaaaP} (\emph{barrier-Free assist as a Pedal}), an
inclusive, foot-free interaction that operates the pedal from the angle of the
player's \emph{head}: a smartphone tracks head pose with on-device augmented-reality
(AR) face tracking and streams a compact command over Bluetooth Low Energy (BLE) to
a pedal device. Supported by patent examination, our central claim is \emph{not} the
head$\rightarrow$pedal architecture (anticipated by prior art) but a quantitative,
user-tunable control law---the patentable ``key'' to a natural, expressive result:
the player presets a small angular dead-zone (offset $3$--$10^\circ$) and a
multiplier ($10$--$50$), which together fix a secondary, pre-adjustable response
speed that reproduces the pianist's intended pedalling. An engineering trick
decouples the fast AR sampling from the slower BLE rate. Two co-equal realizations
share one controller: a non-destructive robotic actuator for acoustic pianos
(\emph{Pro}), anchored by a pneumatic ``airback'' (our coined term for an inflatable
air-braced anchor) that absorbs the reaction force without modifying the instrument;
and an electronic sustain switch for digital pianos (\emph{Switch}). In a
human-subject Auxiliary Pedal Effect Evaluation (APEE) with 15 participants, bFaaaP
significantly increased sustained-tone energy ($p<0.01$) and was statistically
indistinguishable from a player's own foot ($p>0.05$), with no significant difference
across classes; one participant with a leg disability and a tracheostomy performed
successfully. With nothing worn on the face and fast setup, bFaaaP has run in formal
public concerts (2018--2025). We release the full hardware and software as open
source.
\end{abstract}

\noindent\textbf{Keywords:} assistive technology; accessibility; inclusive design;
human--machine interaction; foot-free interaction; head-gesture interface;
robotic actuation; accessible musical instruments; clinical evaluation;
open hardware; Bluetooth Low Energy.

% =====================================================================
\input{draft_sections/body}

% =====================================================================
\section*{Acknowledgements}
We thank Yasuhiro Ono for his advice on AI programming, and Taguchi for
contributing the KiCad schematic and electronics of the Pro device. We are grateful to the
Institute of Science Tokyo and to the owner couple of MUSICASA
(\url{https://www.musicasa.co.jp}) for kindly providing venues for our
demonstrations and concerts. We sincerely thank the participants of the Auxiliary
Pedal Effect Evaluation (APEE)---the adults, children, and players with
disabilities, and their families---for generously taking part and sharing their
feedback. We also thank the bFaaaP and Platanus members and
collaborators, and the performers and audiences of the demonstration events.
Caricature illustrations of the team are by Saki Shiokawa.

\section*{Funding}
This bFaaaP project was supported by Shishido \& Associates.

\section*{Ethics}
The Auxiliary Pedal Effect Evaluation (APEE) involved human participants: adults,
children aged 7--11, and people with disabilities. Participation was voluntary, and
informed consent was obtained in writing for every participant. Adult participants gave
their own written informed consent. For the children, a parent or guardian confirmed
written informed consent (arranged through a piano teacher who assisted the study), and
the child signed the consent form themselves. Participants with disabilities took part
with the written consent of a parent or guardian, who also accompanied them and provided
transport to and from the sessions. Any participant could stop or withdraw at any time,
and the tasks (playing short passages on a piano) posed no more than minimal risk. The
authors are independent practitioners and are not affiliated with an institution that
operates an institutional review board (IRB); no formal IRB review or approval number is
therefore available. The study was nonetheless conducted following the ethical principles
of the ACM Publications Policy on Research Involving Human Participants and
Subjects---minimizing potential harm and protecting participants' privacy and right to
self-determination. All reported data are anonymized (Appendix~A), and no personally
identifying information is included.

\section*{Conflict of interest/Competing interests}
T.S.\ is a chief technology officer at SeemeData Labs, Inc.\ and chief Japanese
patent attorney at Shishido \& Associates. T.S., M.O., and H.N.\ are among the
inventors on the patents underlying bFaaaP (JP~6726319 and JP~7004771;
PCT~WO~2019/176164), which are held by T.~Shishido and Ootaki \& Architects, and
are involved in its commercialization (the \emph{bFaaaPSwitch} iOS application and
the build-to-order pedal device); \emph{bFaaaP} is a registered trademark. The
authors otherwise declare no competing interests.

\section*{Patent availability}
The control method is protected by JP~6726319~B2 and JP~7004771~B2 (priority basis:
PCT~WO~2019/176164~\cite{pct2019}). As a matter of policy the authors intend to license the
patents \emph{free of charge} for genuinely public/open uses and, in particular,
for products or services that enable inclusive social participation by people with
disabilities---even commercial ones. Please contact the corresponding author.

\section*{Data and code availability}
The iOS application source, device firmware, mechanical (CAD/3D-print) designs,
documentation, and the patent file-wrapper materials underlying the APEE data are
openly available in the project repository~\cite{repo}. The intended release
licensing (final decision pending) is a three-layer scheme: \emph{software}
(iOS app and firmware) under the \textbf{Apache License 2.0} (which carries an
explicit patent grant), \emph{hardware} designs (CAD/3D-print/schematic) under
\textbf{CERN-OHL-W-2.0}, and \emph{documentation} under \textbf{CC-BY-4.0};
practising the patented invention in a device is governed by the separate patent
policy above.

% =====================================================================
\input{draft_sections/appendix_apee_data}

% =====================================================================
\bibliographystyle{unsrt}
\bibliography{refs}

\end{document}

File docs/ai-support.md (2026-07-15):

# 🙋 Getting help — GitHub Discussions

> 🌐 **English** · [日本語](../i18n/ja/docs/ai-support.md) · [Deutsch](../i18n/de/docs/ai-support.md)

Building bFaaaP yourself? **Ask in [GitHub Discussions](https://github.com/bfaaap/bfaaap_opensource/discussions) (Q&A).**
This is a **community space**: post your build or usage question, and the bFaaaP community and team
help answer it using this repository's own open materials — build guides, schematics, firmware, and
the parts list. Everything you need to build bFaaaP is here in the open, and it stays free.

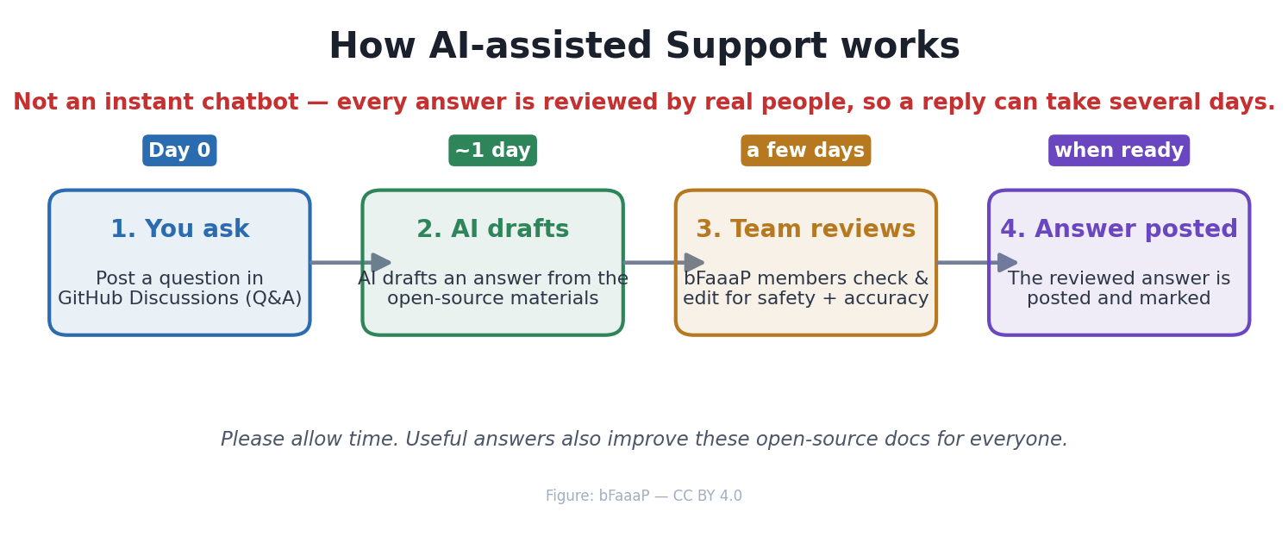
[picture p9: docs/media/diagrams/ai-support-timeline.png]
How help works — a timeline


## ⏳ It is **not** an instant chatbot

Answers are written by **real people** (the bFaaaP community and team — e.g. Shishido and Narusawa),
so **a reply can take some time.** That review by real people is the point: it keeps answers
trustworthy on things that matter — wiring, 24 V power, Bluetooth/radio rules, and assistive‑device
safety. Please be patient and kind — this is a volunteer, community‑run project.

| Stage | What happens | Rough timing |
|---|---|---|
| **1. You ask** | Post a question in GitHub Discussions (Q&A) | Day 0 |
| **2. Community & team help** | Members answer using this repository's open materials | a few days |
| **3. Answer posted** | The answer is posted (and marked as the answer) | when ready |
| **4. Docs improve** | Useful answers are folded back into these docs | when ready |

Useful questions often **improve these docs** too — so your question helps everyone who
builds bFaaaP next.

## Two tracks: answerable now vs. needs the makers

When your question arrives, it tends to fall into one of two tracks:

- **① Answerable now** — the answer is already in this repository (build guides,
  schematics, firmware, the parts list). The community can point you straight to it.
  *Most questions are here, and these are the fastest.*
- **② Needs the makers** — the answer needs information only the device makers have yet
  to publish (e.g. an exact mechanical part number, or the next motor choice). We forward
  your question to them; once they answer we post it **and add it to the docs**, so the
  next builder finds it directly. *These take a little longer.*

Either way your question helps — track ② answers become new documentation.

> 🎭 **How bFaaaP was built in the open:** [**bFaaaP — AI & Team, Live**](ai-team-live.md) — a
> behind‑the‑scenes **record** of an earlier chapter, when AI teammates (Ponte and Harmonia) drafted
> answers and ideas for the team to review as we built bFaaaP **together** (figures, illustrations, and
> firmware reviewed live by the team). We keep it as a record of the project's story. A shorter
> single‑question example: [**"Which motor can replace the EOL one?"**](ai-support-example-pro-motor.md).

## 🧹 What we answer — a curated Q&A

To keep this a high‑signal resource for builders, **the bFaaaP team curates new questions**, and we
do this **in the open** — here's the deal:

- **We prioritize questions that help someone build, reproduce, debug, or improve bFaaaP** — including
  genuine **design ideas**, clear **bug reports**, and **show‑and‑tell** of your build. The useful ones
  become new docs.
- **Detail helps.** Say what you're building, what you tried, your parts/boards, and add an **error
  message or photo** — detailed questions get better, faster answers.
- **Be kind and constructive.** This is **assistive technology**; empathy is our foundation. We follow a
  simple code of conduct.
- **We remove noise.** **Spam, off‑topic posts, hostile/uncivil content, and automated or bulk questions**
  (e.g. bots or other AIs mass‑posting) are hidden or removed and won't be answered.
- **If a question is unclear, we ask — we don't reject.** So if you're a genuine builder, you'll always
  get a reply, even if it's a friendly request for more detail.

*Curation is by the bFaaaP team — transparent, and always erring toward helping a real builder.*

## How to ask a good question

- Say whether it's about the **iOS app, the Pro device, or the Switch device**.
- Include **what you've tried**, your parts/boards, and any **error message or photo**.
- For mechanical parts, mention your **3D printer** and the **part name**.
- Ask in **any language** — we reply in the language you used.

→ **[Open a Q&A discussion](https://github.com/bfaaap/bfaaap_opensource/discussions)**

> ℹ️ Answers are general information to support DIY reproduction/improvement, provided **at
> your own risk**. bFaaaP's patents are licensed free of charge for public‑interest,
> inclusive use. Please mind local regulations (radio law for BLE, medical/assistive‑device
> rules) and electrical safety (24 V).

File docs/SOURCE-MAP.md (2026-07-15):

# Source map — which files back each explanation

> 🌐 **English** · [日本語](../i18n/ja/docs/SOURCE-MAP.md) · [Deutsch](../i18n/de/docs/SOURCE-MAP.md)

A single index of **what is explained where**, and **which source file, CAD model, schematic,
code, photo, or figure it corresponds to** (with its location in this repository). Use this to
jump from any topic to its authoritative files. All paths are relative to the repo root
(`github_opensource/`).

> Legend: 📄 doc · 💻 code · 📐 CAD/3D · ⚡ schematic/electronics · 📊 figure (generated) · 📷 photo

## 1. The whole system / how it works
| Topic | 📄 Explanation | Sources & figures |
|---|---|---|
| Concept & data flow | [`docs/how-it-works.md`](how-it-works.md) | 📊 [`docs/media/diagrams/architecture.png`](media/diagrams/architecture.png) · 📊 [`media/illustrations/intl-how-it-works.png`](media/illustrations/intl-how-it-works.png) |
| Control law (head angle → pedal) | [`docs/how-it-works.md`](how-it-works.md), patent guide | 📊 [`docs/media/diagrams/control-law.png`](media/diagrams/control-law.png) · 📄 [`bfaaap_patent_info/general_description/`](../bfaaap_patent_info/general_description/README.md) |
| AR↔BLE timing (pacing) | [`ios-app/DESIGN-HIGHLIGHTS.md`](../ios-app/DESIGN-HIGHLIGHTS.md) | 📊 [`docs/media/diagrams/rate-decoupling.png`](media/diagrams/rate-decoupling.png) |
| Glossary of terms | [`docs/GLOSSARY.md`](GLOSSARY.md) | — |

## 2. iOS app
| Topic | 📄 Explanation | 💻 Code / 📷 figures |
|---|---|---|
| Build & run | [`ios-app/BUILD.md`](../ios-app/BUILD.md), [`docs/build/ios.md`](build/ios.md) | 💻 [`ios-app/src/bFaaaPSwitch1/`](../ios-app/src/bFaaaPSwitch1/) (Xcode project) |
| Code structure | [`ios-app/CODE-STRUCTURE.md`](../ios-app/CODE-STRUCTURE.md) | 💻 `ios-app/src/bFaaaPSwitch1/` |
| Head-angle (ARKit) | [`ios-app/DESIGN-HIGHLIGHTS.md`](../ios-app/DESIGN-HIGHLIGHTS.md) | 💻 `…/ARKit/` |
| BLE send + pacing (the "100 ms" trick) | [`ios-app/DESIGN-HIGHLIGHTS.md`](../ios-app/DESIGN-HIGHLIGHTS.md), [`ios-app/BLE-CONNECTION-FLOW.md`](../ios-app/BLE-CONNECTION-FLOW.md) | 💻 `…/BLEManager/` |
| App Store assets | [`ios-app/app-store/`](../ios-app/app-store/) | 📷 `ios-app/app-store/screenshots/` |

## 3. Firmware (the device boards)
| Topic | 📄 Explanation | 💻 Code |
|---|---|---|
| Overview / which sketch to use | [`device-pro-acoustic/firmware/README.md`](../device-pro-acoustic/firmware/README.md) | — |
| **Main board (Pico) — reference** | [`firmware/DESIGN-HIGHLIGHTS.md`](../device-pro-acoustic/firmware/DESIGN-HIGHLIGHTS.md), [`firmware/CODE-STRUCTURE.md`](../device-pro-acoustic/firmware/CODE-STRUCTURE.md) | 💻 `device-pro-acoustic/firmware/pico/bFaaaP_autopro_pico_v039B_20250725.ino` |
| BLE board (nRF52) | [`firmware/README.md`](../device-pro-acoustic/firmware/README.md) | 💻 `device-pro-acoustic/firmware/pico/bFaaaPpro_BLE_2024010309_bord_A.ino` |
| **Switch device (nRF52, standalone on/off)** | [`switch firmware/README.md`](../device-switch-electronic/firmware/README.md) | 💻 `device-switch-electronic/firmware/bFaaaPSW_20211007_for_ex_fs_J_13_ymc/` |
| Stepper successor (⚠ early, do not build) | [`HARDWARE-AVAILABILITY.md`](../device-pro-acoustic/HARDWARE-AVAILABILITY.md) | 💻 `…/pico/bFaaaP_autopro_pico_v052B_step_20251111.ino` |
| Motor comms library | [`firmware/README.md`](../device-pro-acoustic/firmware/README.md) | 💻 `device-pro-acoustic/firmware/libraries/iq-module-communication-arduino/` |
| Flashing / toolchain | [`docs/toolchain/README.md`](toolchain/README.md) | — |
| Confirmed wiring & calibration notes | [`device-pro-acoustic/DISCORD-FINDINGS.md`](../device-pro-acoustic/DISCORD-FINDINGS.md) | — |

## 4. Electronics / wiring
| Topic | 📄 Explanation | ⚡ schematic / 📷 photo |
|---|---|---|
| Parts list (boards, motor, connectors) | [`hardware/PARTS-REFERENCE.md`](../device-pro-acoustic/hardware/PARTS-REFERENCE.md) | ⚡ [`hardware/reference/fortiq42_interface_bfaaap.png`](../device-pro-acoustic/hardware/reference/fortiq42_interface_bfaaap.png) |
| Circuit schematic | [`hardware/schematic/README.md`](../device-pro-acoustic/hardware/schematic/README.md) | ⚡ `hardware/schematic/schematic_2025-03-05_kicad.png` · `block-diagram.png` · `power-supply-options.png` |
| Pin map (GP4/5 motor, GP2/3 HX711, GP12 pump, ADC0 slider) | [`firmware/DESIGN-HIGHLIGHTS.md`](../device-pro-acoustic/firmware/DESIGN-HIGHLIGHTS.md) + the `.ino` | ⚡ schematic above |
| I/O panel & power | [`hardware/photos/README.md`](../device-pro-acoustic/hardware/photos/README.md) | 📷 `hardware/photos/pro_io_panel.jpg` · `pro_power_connector.jpg` · `pro_printed_io_panels.jpg` |

## 5. Mechanics — CAD, 3D print, assembly
| Topic | 📄 Explanation | 📐 CAD/STL · 📊 figure · 📷 photo |
|---|---|---|
| Assembly guide & BOM | [`device-pro-acoustic/assembly/README.md`](../device-pro-acoustic/assembly/README.md), [`docs/build/pro.md`](build/pro.md) | 📊 [`docs/media/diagrams/pro-build-flow.png`](media/diagrams/pro-build-flow.png) |
| Drive mechanism (motor→belt→screw→rod) | [`docs/build/pro.md`](build/pro.md) | 📐 `hardware/cad/from-discord-2025/bfaaap_belt_gotai14.FCStd` · 📊 `docs/media/diagrams/pro-mechanism.png` · 📷 `hardware/photos/pro_components_airback_and_drive.jpg` |
| Editable CAD (curated) | [`hardware/cad/README.md`](../device-pro-acoustic/hardware/cad/README.md) | 📐 `hardware/cad/*.FCStd` |
| Editable CAD (full Discord archive) | [`hardware/cad/from-discord-2025/README.md`](../device-pro-acoustic/hardware/cad/from-discord-2025/README.md) | 📐 `hardware/cad/from-discord-2025/*.FCStd` |
| 3D-print files & settings | [`hardware/3d-print/README.md`](../device-pro-acoustic/hardware/3d-print/README.md) | 📐 `hardware/3d-print/*.stl`, `*.3mf` ; new housing `hardware/3d-print/from-discord-2025/bFaaaP_{AA,CC,DD,E_a,FF}*.stl` |
| Airback anchoring | [`hardware/airback/README.md`](../device-pro-acoustic/hardware/airback/README.md) | 📷 `hardware/photos/airback_air_valve.jpg` |
| Mechanical BOM (CAD-derived) | [`docs/build/pro.md`](build/pro.md) §BOM | 📐 from `hardware/cad/from-discord-2025/` (BREP dimensions) |

## 6. Calibration & operation
| Topic | 📄 Explanation | source |
|---|---|---|
| Setup & daily operation | [`docs/operation/README.md`](operation/README.md) | 🎥 [video](https://www.youtube.com/watch?v=_9YopbCYTmI) |
| End-user manual | [`docs/user-manual/README.md`](user-manual/README.md) | 🎥 [Switch manual](https://youtu.be/XOVENtBsOp4) |
| Pressing-force calibration (DIP, 20–35 W) | [`DISCORD-FINDINGS.md`](../device-pro-acoustic/DISCORD-FINDINGS.md) | 💻 firmware `…v039B….ino` |

## 7. Story, people, research, legal
| Topic | 📄 Explanation | sources |
|---|---|---|
| The story | [`docs/story.md`](story.md) | 📷 members, posters; 🎥 videos |
| History / Members / Videos | [`docs/HISTORY.md`](HISTORY.md) · [`docs/members/`](members/) · [`docs/videos/`](videos/) | 📷 `docs/members/*` |
| Research preprint | [`bfaaap_arxiv_latex/README.md`](../bfaaap_arxiv_latex/README.md) | `bfaaap_arxiv_latex/main.tex`, `figures/` |
| Patents / trademark | [`bfaaap_patent_info/`](../bfaaap_patent_info/README.md) | prosecution PDFs |
| Licensing | [`../LICENSE`](../LICENSE), `LICENSES/` | — |
| Community Support | [`docs/ai-support.md`](ai-support.md) | 📊 `docs/media/diagrams/ai-support-timeline.png` |
| Support / donate | [`../SUPPORT.md`](../SUPPORT.md) | 📊 `media/illustrations/intl-support.png` |

## 8. Generated figures (what each is) — `docs/media/diagrams/`
| File | Shows | Made with |
|---|---|---|
| `architecture.png` | iOS → BLE → Pico → motor data flow | (reused project figure) |
| `control-law.png` | head angle → pedal mapping (dead-zone, multiplier, hysteresis) | matplotlib |
| `rate-decoupling.png` | AR sampling vs BLE send timing | (reused project figure) |
| `pro-mechanism.png` | drivetrain + airback mechanism | (reused project figure) |
| `pro-build-flow.png` | the 8 Pro build steps → files each uses | matplotlib |
| `ai-support-timeline.png` | the community support process timeline | matplotlib |

Illustrations (`docs/media/illustrations/`) and full credits/licensing: [`docs/media/CREDITS.md`](media/CREDITS.md).

Cited references — saved copies of the open-access papers and the patents, plus stable links and
access dates for everything else: [`docs/references/`](references/README.md).

> Note: AI figures are generated by the private tooling in `AI-assistedSupport/` (outside this
> repo); only the **output images** are committed here. Photos are committed directly (no external
> hot-links).

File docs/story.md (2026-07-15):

# The bFaaaP Story 🎹

> 🌐 **English** · [日本語](../i18n/ja/docs/story.md) · [Deutsch](../i18n/de/docs/story.md)

*From one person's wish — to a foot‑free piano pedal that **anyone can build**.*

A pianist playing, the pedal pressed by a small friendly device

> **bFaaaP** = **b**arrier‑**F**ree **a**ssist **a**s **a** **P**edal — an AI assistive
> piano‑pedal system. Tilt your head a little, and the sustain pedal goes down. No feet
> required. This page tells the story of how it came to be, who built it, and where you
> can *see* and *hear* it. New here? Start with [How it works](how-it-works.md) and the
> [glossary](GLOSSARY.md); ready to make one? jump to [Build it yourself](build/).

---

## 1. It began with a wish (2018)

In **January 2018**, a **wheelchair user** — a client of the architect
**Masahiro Ootaki** — said something simple and profound:

> *"I'd like to motorize the piano's pedal so I can press it."*

Seated at the piano, they could play the keys beautifully — but could not reach the
pedals, and without the pedal the music lost its bloom. That single wish became bFaaaP.

The very first prototype, **"bFaaap‑1"** (*piano‑pedal trial #1*, **10 Feb 2018**), was a
white box weighted with concrete and stuffed with wiring. The philosophy from day one was
the engineer's favourite: *first, build **something** that moves.*

## 2. Glasses, sensors, and a patent (bFaaaP1–4)

The early system had two halves, run by a microcontroller (the Arduino / M5Stack · ESP32
era — bFaaaP4 even wore a hand‑made wooden enclosure):

- a **head‑motion sensor** — a 9‑axis IMU mounted on an **eyeglass frame**, reading the
  gentle fore/aft tilt of the head, and
- an **actuator** sitting in front of the pedal.

The core idea — a head‑angle **offset (dead‑zone)** and a **multiplier**, which together fix a
secondary **response speed** — was filed as a **PCT
international patent** in 2018 and later granted in Japan (**特許第6726319号 / 第7004771号**).
bFaaaP made its public debut around **2019** at a recital of Kyoko Yamaguchi's piano class
*"Fleur"* (MUSICASA, Yoyogi‑Uehara).

## 3. The leap to today: a phone, a tilt, a pedal

The glasses‑mounted sensor was replaced by something almost everyone already owns: a
**smartphone**. Apple's **AR face tracking** now reads the head angle and sends it over
**Bluetooth Low Energy** to a small pedal device (a **Raspberry Pi Pico** + **Adafruit
ItsyBitsy nRF52840**). Two product lines grew from this:

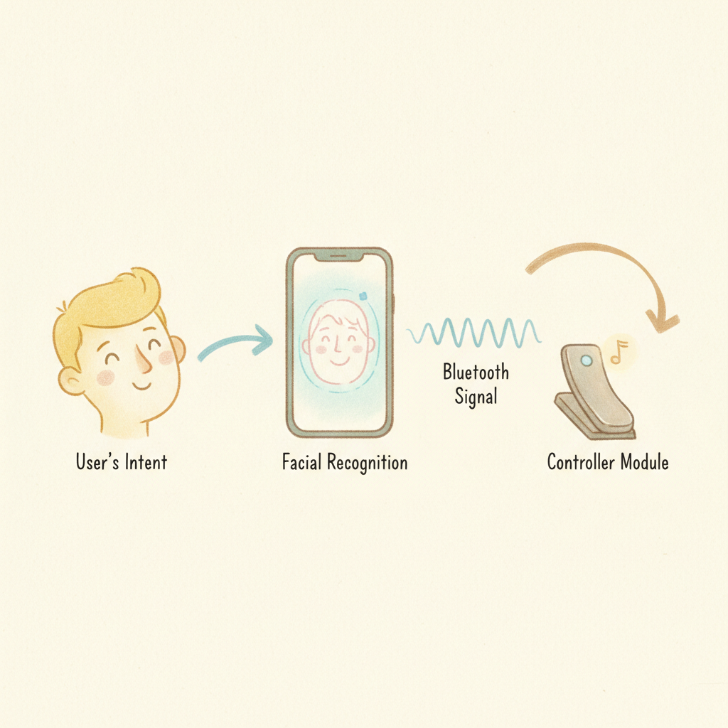
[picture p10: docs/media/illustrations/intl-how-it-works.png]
How it works: your intent → face recognition → Bluetooth → controller


| Line | For | How it presses |
|---|-----|---|
| 🎹 **Pro** | **Acoustic** grand & upright pianos | a small **motor** physically presses the sustain pedal (anchored by an *airback* air‑cushion) |
| 🎛️ **Switch** | **Digital** pianos & keyboards | switches the sustain **electronically** through the pedal jack — tiny, no motor |

Pro for acoustic pianos, Switch for digital pianos

## 4. The people behind bFaaaP 👋

bFaaaP is built by the **Platanus** group — engineers, musicians, a tuner, a composer, and
IP specialists, brought together by one inclusive idea. *Portraits are the project's own
hand‑drawn caricatures by **Saki Shiokawa (塩川紗季)**.*

| | Who | Role |
|---|-----|---|
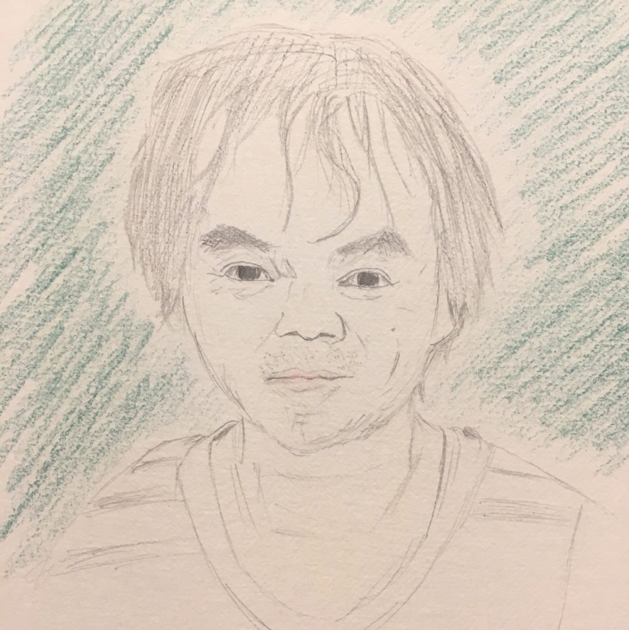
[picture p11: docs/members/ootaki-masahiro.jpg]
Masahiro Ootaki
|  | **Masahiro Ootaki** 大瀧雅寛 | First‑class **architect** (barrier‑free housing); bFaaaP's designer & coordinator — and the one whose client's wish started it all. |
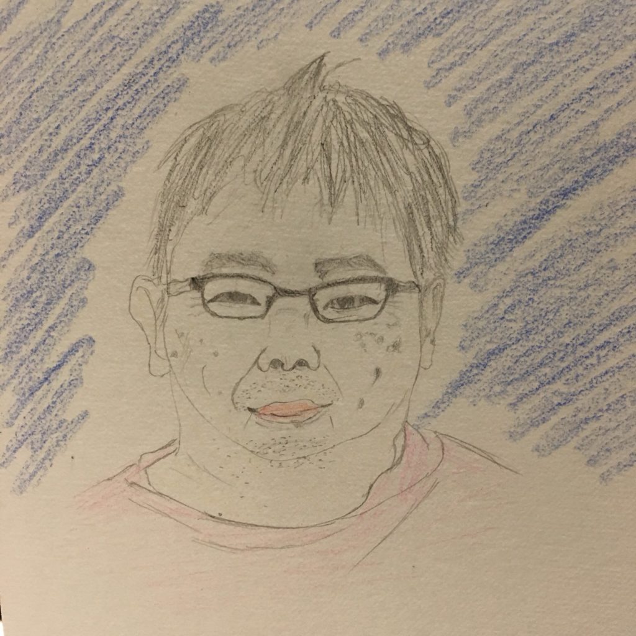
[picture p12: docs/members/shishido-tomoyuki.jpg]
Tomoyuki Shishido
|  | **Tomoyuki Shishido** 宍戸知行 | **iOS app.** Ph.D. & patent attorney, now a Ph.D. student at Institute of Science Tokyo; learned Swift to build bFaaaP. Took up piano at 45. |
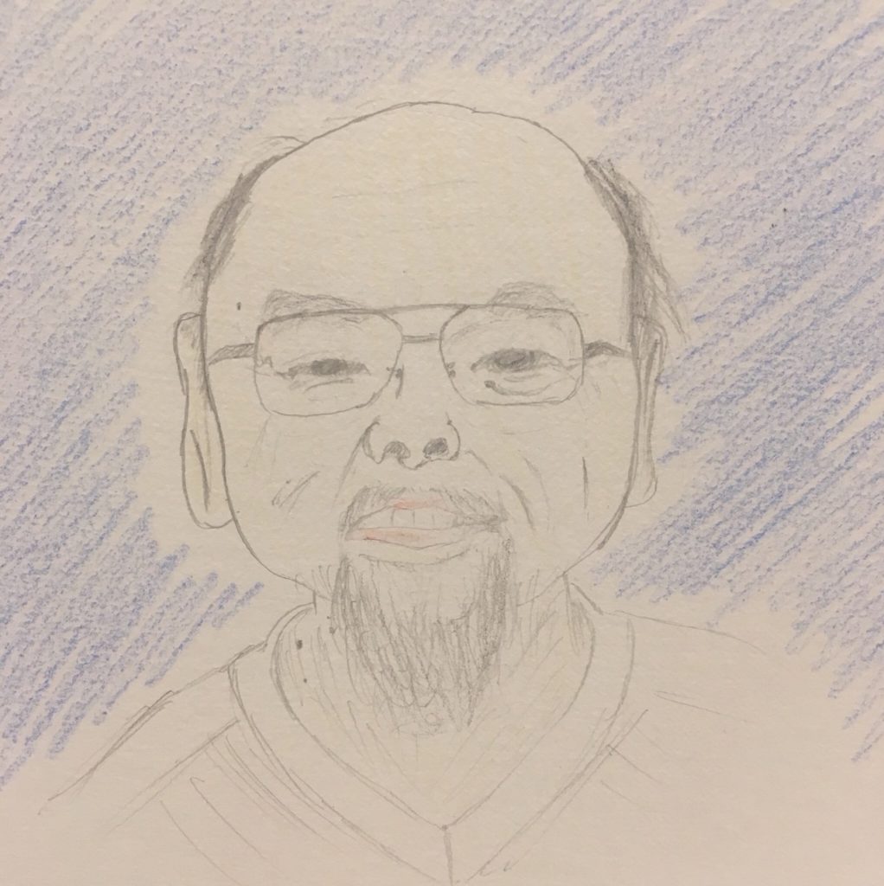
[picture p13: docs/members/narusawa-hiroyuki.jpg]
Hiroyuki Narusawa
|  | **Hiroyuki Narusawa** 成澤博行 | **Pedal device & firmware.** Runs Naru Science Soft; designs and builds the hardware that does the pressing. |
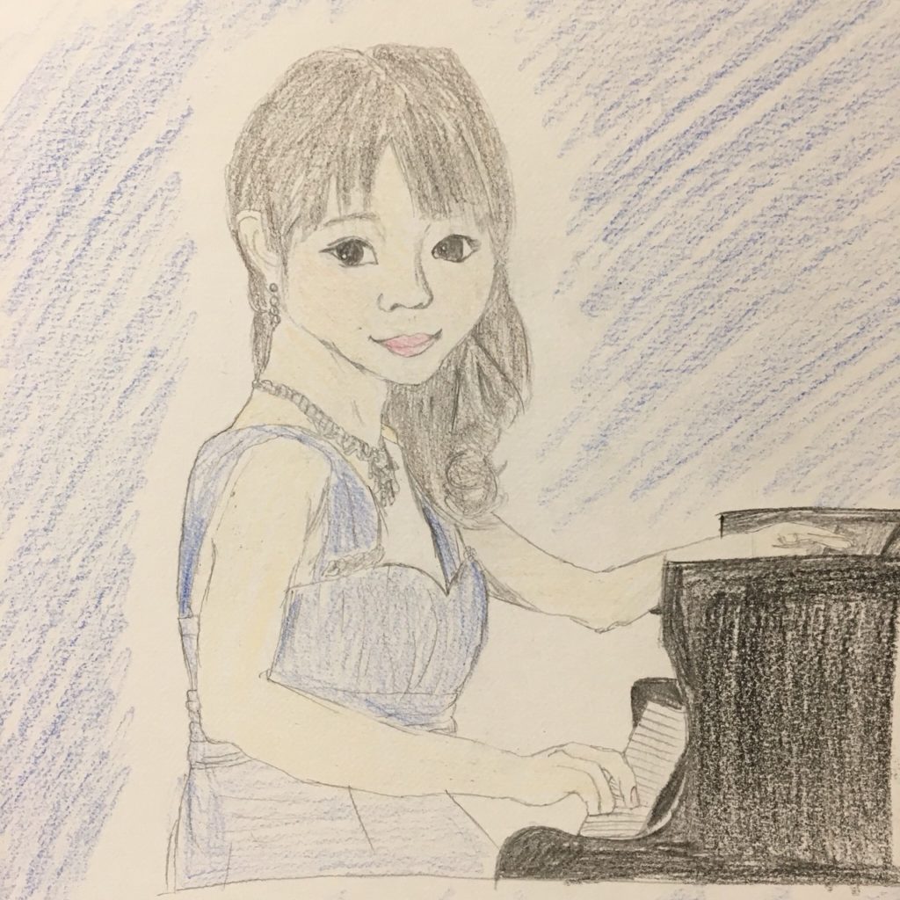
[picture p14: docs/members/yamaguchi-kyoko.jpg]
Kyoko Yamaguchi
|  | **Kyoko Yamaguchi** 山口恭子 | **Piano & pedagogy.** ~15 years teaching; champions a new, IT‑era pedal technique. |
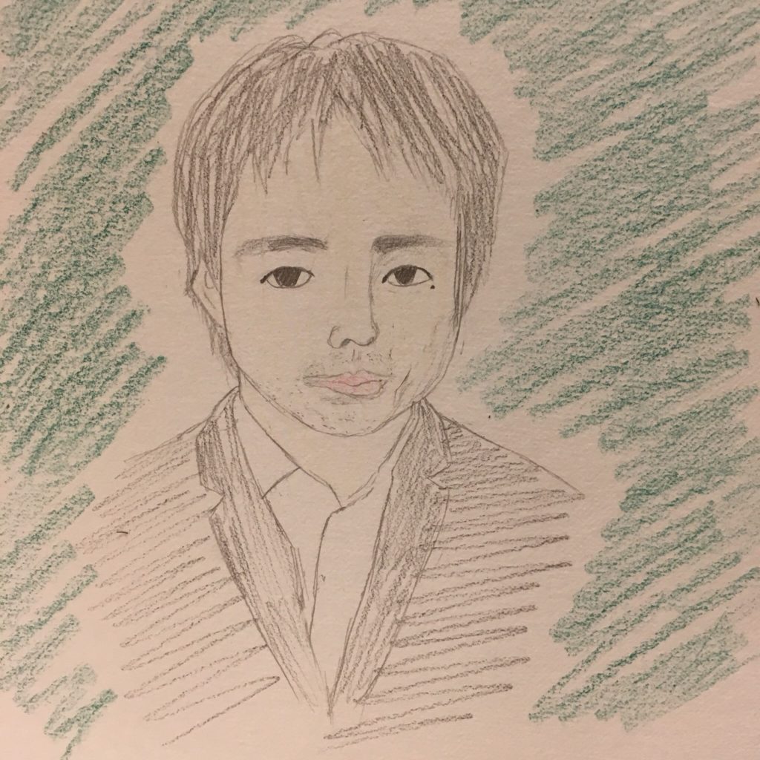
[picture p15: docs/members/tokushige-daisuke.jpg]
Daisuke Tokushige
|  | **Daisuke Tokushige** 徳重大輔 | **Intellectual property.** Patent engineer supporting bFaaaP's patents. |
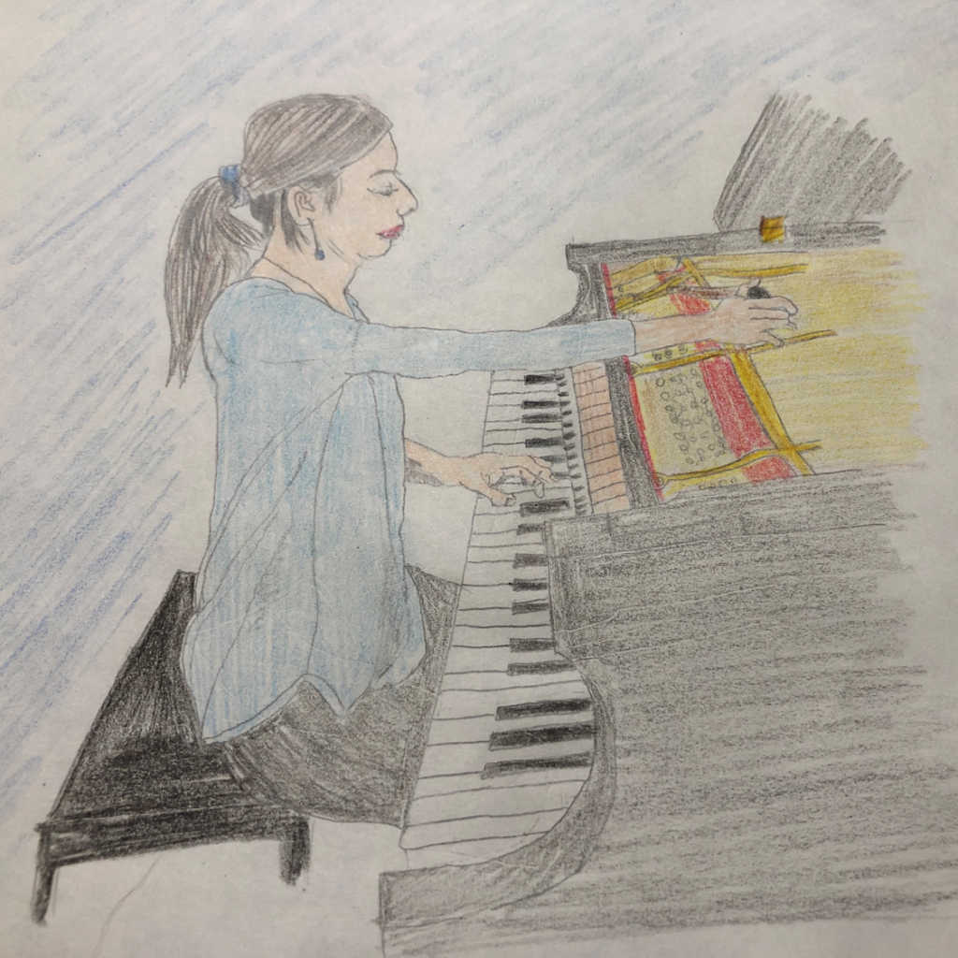
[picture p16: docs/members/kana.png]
kana
|  | **kana** | **Piano tuner.** Sees the pedal + finger technique as one phrase — and bFaaaP as that ideal made real. |
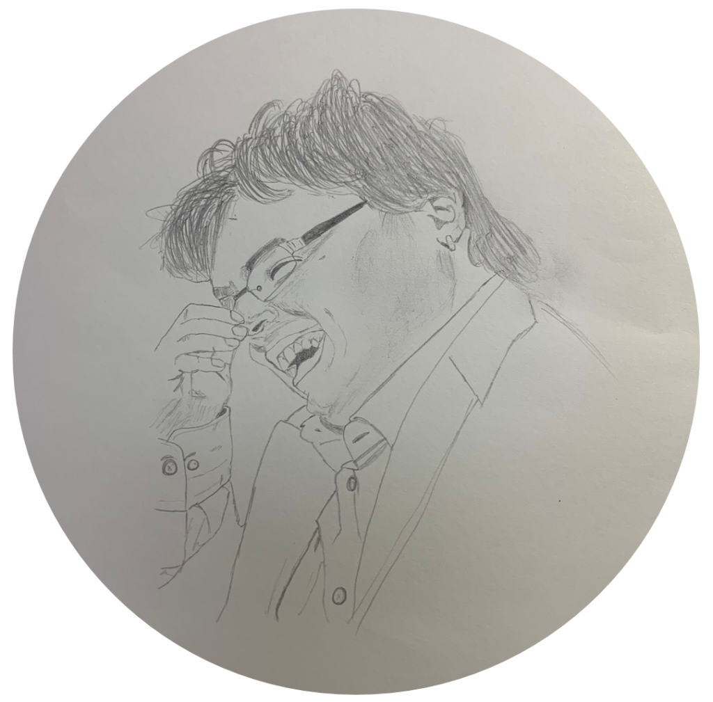
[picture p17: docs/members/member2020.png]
Fehmiju Fati
|  | **Fehmiju Fati** | **Composer / computer music.** International awards; earned a Ph.D. in computer music in Japan; joined KORG sound development; volunteered with bFaaaP, 2019–2023. |
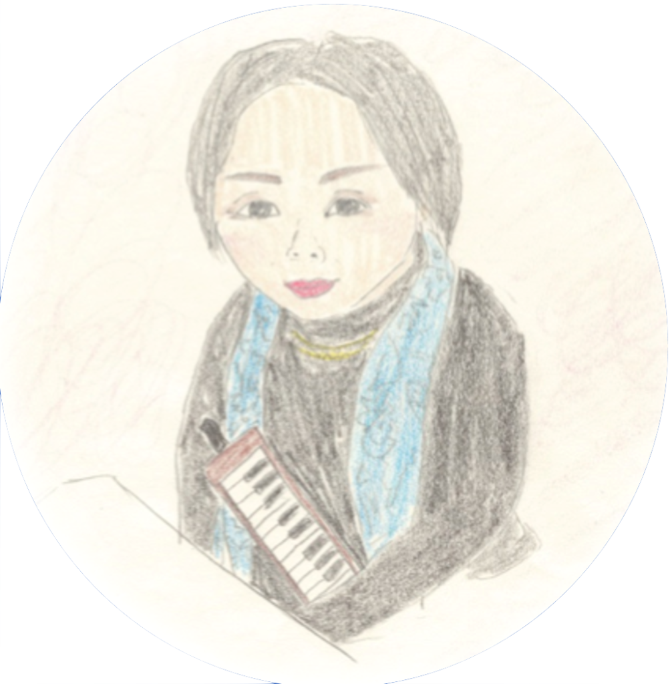
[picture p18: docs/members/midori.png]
Midori
|  | **Midori** | **Music & healthcare.** *"bFaaaP may switch on the heart, too."* |
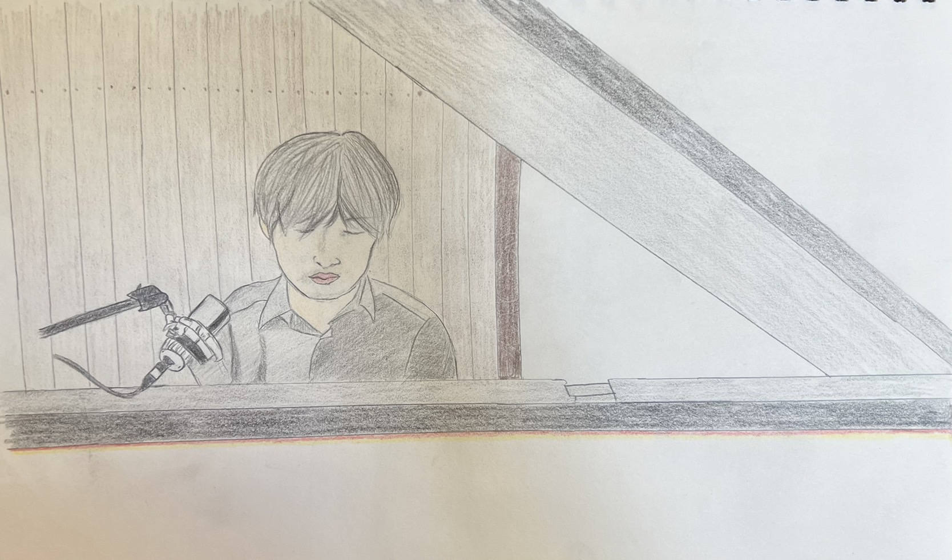
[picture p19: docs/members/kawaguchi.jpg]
Hiroyoshi Kawaguchi
|  | **Hiroyoshi Kawaguchi** 川口洋慶 | **Keyboards & engineering.** Institute of Science Tokyo (System & Control); programming + deep‑learning; piano since age 3. |
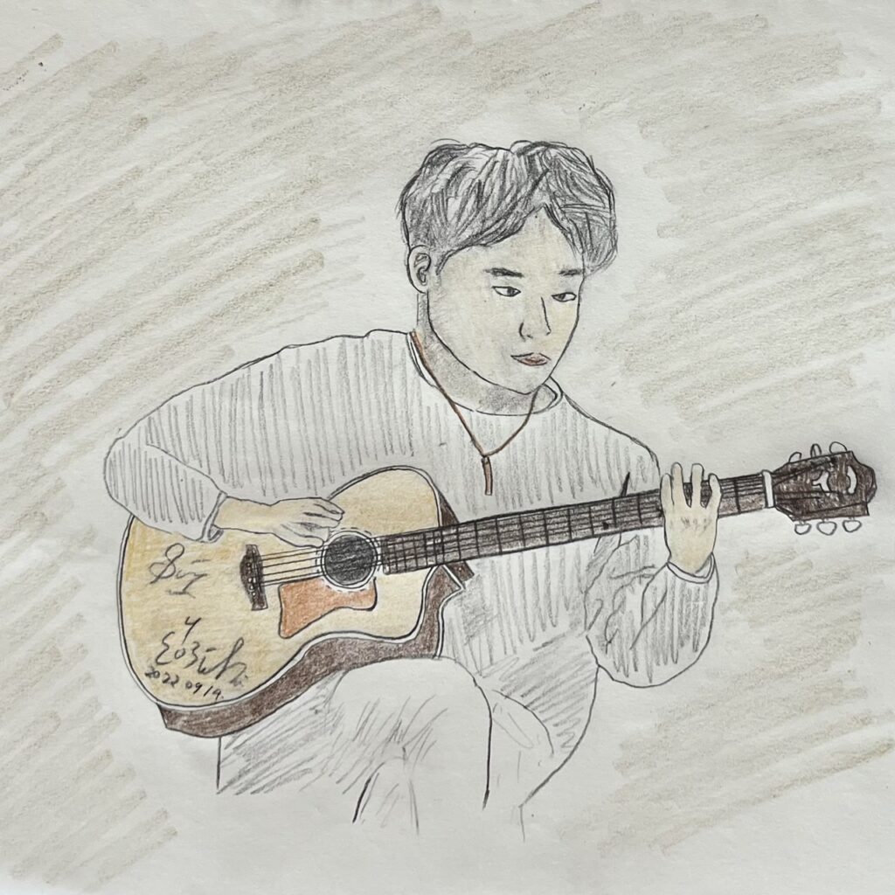
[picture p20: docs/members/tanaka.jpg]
Haruto Tanaka
|  | **Haruto Tanaka** 田中遥斗 | **Electrical engineering.** Institute of Science Tokyo; wants to extend Switch beyond the piano. |
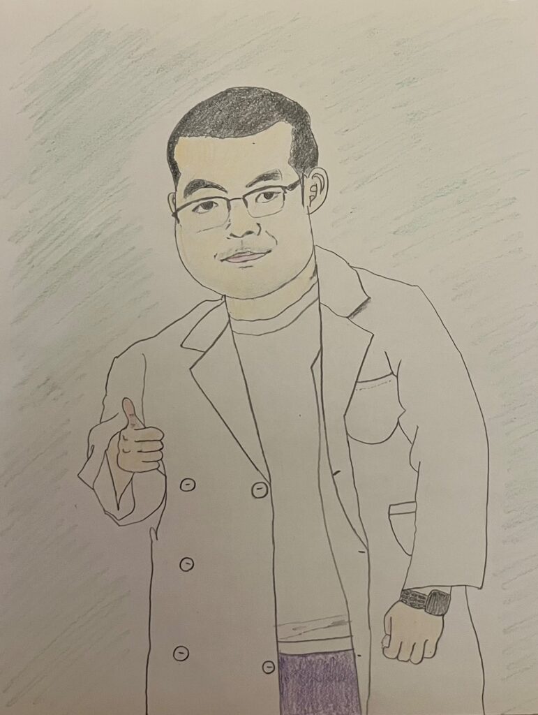
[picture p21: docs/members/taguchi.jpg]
Taguchi
|  | **Taguchi** 田口 | **Software engineering.** Deepening bFaaaP know‑how to improve it from user feedback. |

→ Full bios: [`docs/members/`](members/).

## 5. See it — and hear it 🎬

The best way to understand bFaaaP is to watch real performances. Everything is on the
**[YouTube channel](https://www.youtube.com/channel/UCcAvTy1k8rHs2WrEKPx1amg)**; here are the
highlights by category (newest first).

### 🏆 Start here — two marquee performances
- **▶ [2025 Platanus Suzukake Concert with bFaaaP](https://www.youtube.com/watch?v=V3cXeNW9jXY)** · 72:20
  A full concert on a **grand piano (Pro)** — *and* it includes a **device setup
  walkthrough at 25:01–28:32**. The single best video to understand the Pro line.
- **▶ [Platanus with bFaaaP, 2024 Kodai festival (Institute of Science Tokyo)](https://www.youtube.com/watch?v=Im4jsed1tJQ)** · 55:29
  System intro + members + three pieces on an **electric piano (Switch)**, then a hands‑on
  **workshop** (39:21–54:18).

Platanus with bFaaaP — concert poster
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

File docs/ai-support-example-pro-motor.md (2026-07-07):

# 🧵 A live example: "Which motor can replace the EOL one?"

> 🌐 **English** · [日本語](../i18n/ja/docs/ai-support-example-pro-motor.md) · [Deutsch](../i18n/de/docs/ai-support-example-pro-motor.md)
>
> Part of [AI‑assisted Support](ai-support.md). This page shows **how it actually feels**:
> the **AI proposes an idea from the open data, and the real bFaaaP team reviews and
> supplements it.** Nobody knows the single "right" answer here — that is exactly why the
> human review matters, and why it's fun to watch the answer take shape.

The Pro's original drive motor (**IQ Fortiq M42BLS**) is **end‑of‑life**. A newcomer asked, in
effect: *"What motor + firmware can I actually use to reproduce the Pro today?"* There is **no
settled answer yet** — so the AI did the legwork from current data, and the people who actually
built bFaaaP are weighing in. Here is that thread.

<table>
<tr>
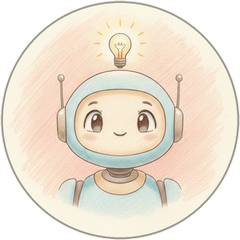
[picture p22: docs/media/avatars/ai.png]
Ponte avatar
<td width="120" valign="top"></td>
<td valign="top">

**🤖 Ponte** &nbsp;·&nbsp; <sub>draft idea from current web data (June 2026) — *unverified*</sub>
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

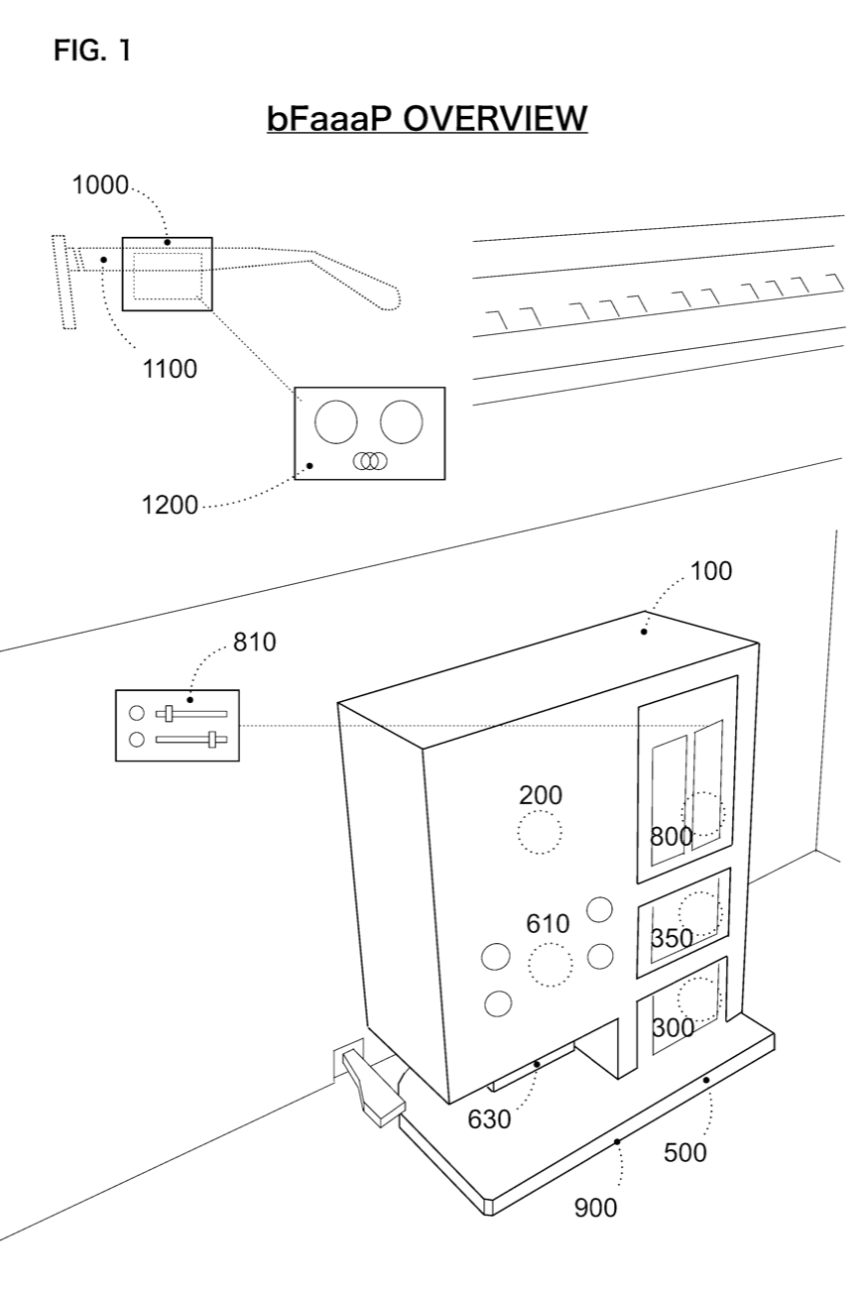
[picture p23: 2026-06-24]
docs/history/bfaaap-1-original/fig1-overview-glasses-sensor.png

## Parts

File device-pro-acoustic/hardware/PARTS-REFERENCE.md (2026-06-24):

# Pro device — parts reference (boards, motor, connectors)

> **Source / attribution.** The parts **data** is from the team's `bfaaapteam`
> repository (`docs/hardware.md`, by Taguchi & H. Narusawa) and the team Discord.
> The reference **figures** in [`reference/`](reference/) are **original
> bFaaaP-project drawings** (CC BY 4.0), redrawn from the public pinouts — the
> earlier third-party images (of uncertain license) were removed.

This is the **authoritative parts list with vendor links** for the IQ (v039B)
reference generation. It supersedes earlier guesses about the BLE board.

## Microcontrollers

| Role | Part | Vendor / link |
|---|---|---|
| **Main board (pedal/motor control)** | **Raspberry Pi Pico** (RP2040) | [raspberrypi.com](https://www.raspberrypi.com/products/raspberry-pi-pico/) · [datasheet](https://datasheets.raspberrypi.com/pico/pico-datasheet.pdf) · bFaaaP pin map: [`reference/pico_pinout_bfaaap.png`](reference/pico_pinout_bfaaap.png) |
| **BLE board (receiver)** — **confirmed** | **nRF52840 BLE board (Akizuki `AE-NRF52840`, `g117484`)** ✅ | [akizukidenshi g117484](https://akizukidenshi.com/catalog/g/g117484/) · [datasheet](https://akizukidenshi.com/goodsaffix/AE-NRF52840.pdf) |
| **BLE board (receiver)** — alternative | **Adafruit Feather nRF52840 Express** (ID 4062) | [adafruit.com/product/4062](https://www.adafruit.com/product/4062) · [guide](https://learn.adafruit.com/introducing-the-adafruit-nrf52840-feather) |

> **BLE board (confirmed by the device co‑author, 2026‑06‑14):** the shipping board
> is the **Akizuki `AE-NRF52840` (g117484)** — chosen because it is **cheaper**,
> uses the **same BLE module**, and reports the **same board ID** (the Adafruit
> Feather nRF52840 is a compatible alternative). It is **not** the ItsyBitsy: the
> ItsyBitsy/DotStar appears in the **Switch** firmware's colour‑LED routine, while
> the **Pro** BLE firmware is "the Switch BLE code minus the LED and sleep
> routines," so the Pro board needs no DotStar.

## Drive motor

| Item | Detail |
|---|---|
| **Motor** | **IQ Fortiq BLS42** (a.k.a. M42BLS / `IQ-FORTIQ-M42BLS-100`, 100 W) — [Crowd Supply](https://www.crowdsupply.com/iq-motion-control/iq-fortiq-bls42) · [Vertiq docs](https://iqmotion.readthedocs.io/en/latest/modules/fortiq_42XX.html) · [datasheet](https://iqmotion.readthedocs.io/en/latest/_downloads/c01d03f5e3ec159b4621b16c13126158/fortiq_datasheet.pdf) |
| **Electrical interface** | CANL, CANH, ADC, GPIO1‑3, HPO (7‑pin signal) + V‑/V+; the `H1_RX` / `H2_TX` pair is used as **serial** (also supports PWM/Dir, Step). Authoritative pinout: [Vertiq docs](https://iqmotion.readthedocs.io/en/latest/modules/fortiq_42XX.html); our redrawn wiring: [`reference/fortiq42_interface_bfaaap.png`](reference/fortiq42_interface_bfaaap.png). |
| **Signal terminal** | Same Sky (CUI) **TBL009-254-07GY-2GY** (7‑pos, 2.54 mm, screwless, 26–18 AWG) |
| **Power terminal** | Same Sky (CUI) **TBLH10-350-02BK** (2‑pos, 3.5 mm, 24–16 AWG) |
| **3‑pin header** | generic ("Dupont") 3P housing ([akizuki g112152](https://akizukidenshi.com/catalog/g/g112152/)) |
| **Status (per device co‑author)** | **EOL** → successor = closed‑loop stepper (DRV8825‑compatible interface), **specific model undecided**. |

## Power & other parts (confirmed in Discord)

- **Supply:** **24 V** for the IQ motor (within the motor's spec); 12 V batteries
  in series are usable for venues without AC; portable power stations work for
  outdoor concerts. *(Next‑gen idea: a single 24 V supply, generating 5 V
  internally if the motor current doesn't disturb the 5 V rail.)*
- **Power connector (prototype):** an **M15‑type** connector (the kind used for
  radio‑transceiver microphone jacks); not critical — other connectors are fine,
  but the **high current** matters.
- **Air pump:** the **rubber‑visible side of the metal valve is the air input**.
- **Pressing‑force calibration:** by **motor power**; threshold **20–35 W**, set by
  a **DIP switch** (base 20 W + DIP, 1 W steps), **piano‑dependent**; a **50 mm**
  travel cap prevents the push‑rod from being driven out (firmware v039B comment).
- **Upper‑limit input:** a **variable resistor / slide volume** read on the Pico
  **ADC0 (GP26)**.

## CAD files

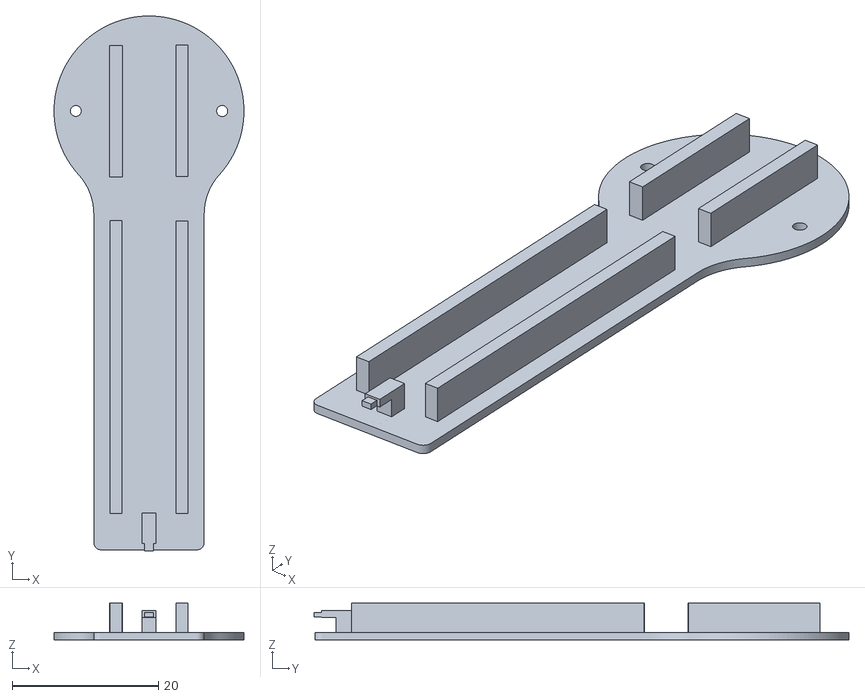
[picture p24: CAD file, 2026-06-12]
device-pro-acoustic/hardware/3d-print/bfaaap_auto_box_AB_a-Body001.stl
26.0 x 73.2 x 5.00

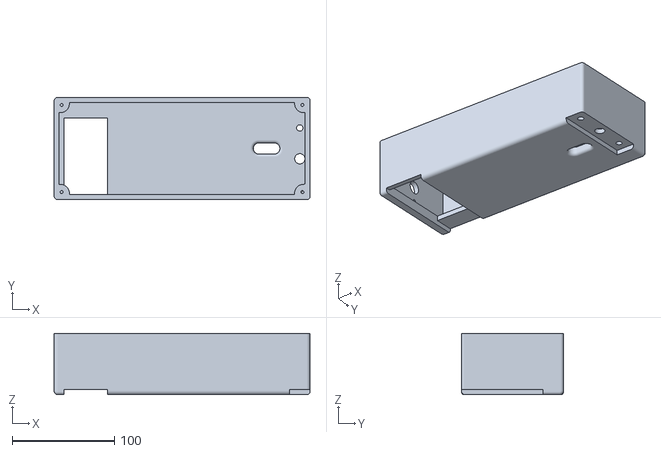
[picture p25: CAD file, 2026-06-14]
device-pro-acoustic/hardware/3d-print/from-discord-2025/bFaaaP_CC-CC.stl
250.0 x 100.0 x 60.0

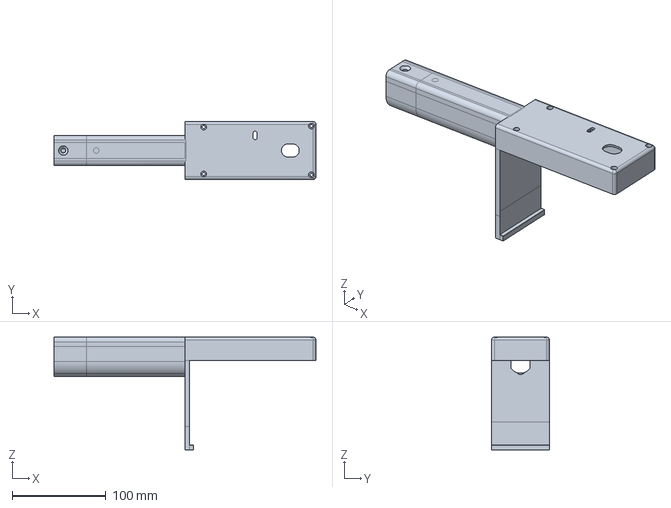
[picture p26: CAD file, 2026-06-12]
device-pro-acoustic/hardware/cad/bFaaaP_BB_a.FCStd
280.1 x 62.1 x 120.5 mm

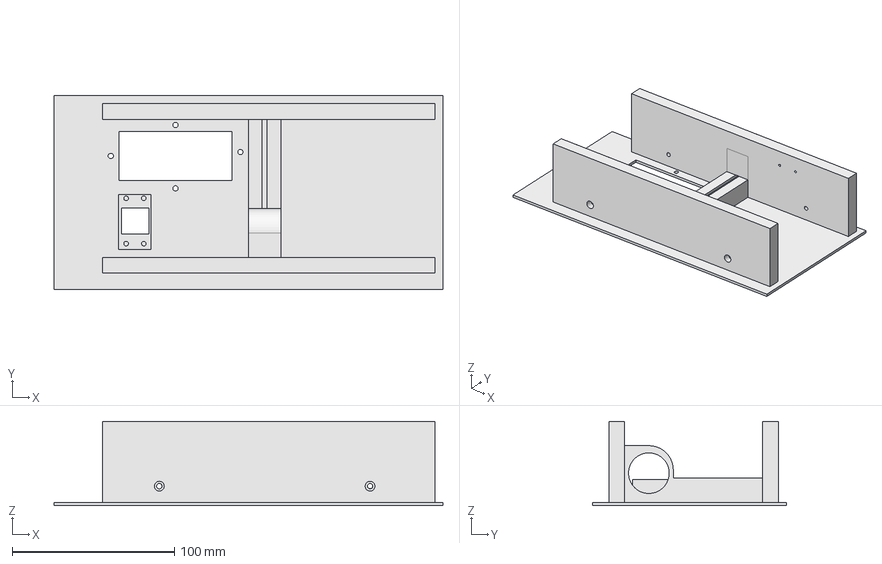
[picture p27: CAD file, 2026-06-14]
device-pro-acoustic/hardware/cad/from-discord-2025/bfaaap_side_panel.FCStd
240.0 x 120.0 x 52.0 mm

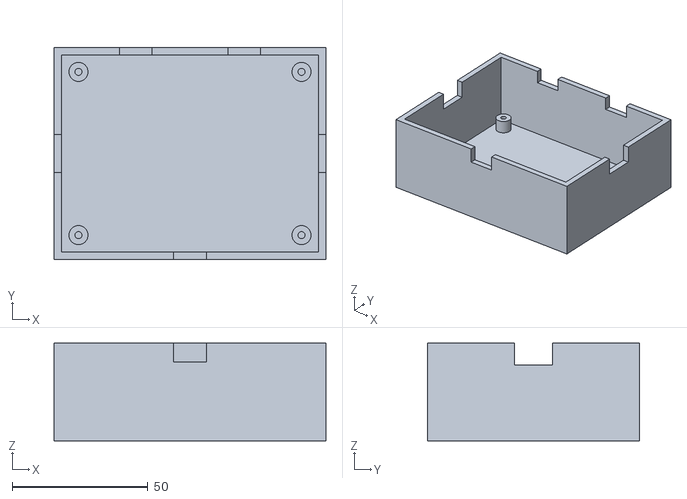
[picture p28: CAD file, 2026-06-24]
device-pro-acoustic/hardware/reference-design/pro-ebox-base.stl
100.0 x 78.0 x 36.0

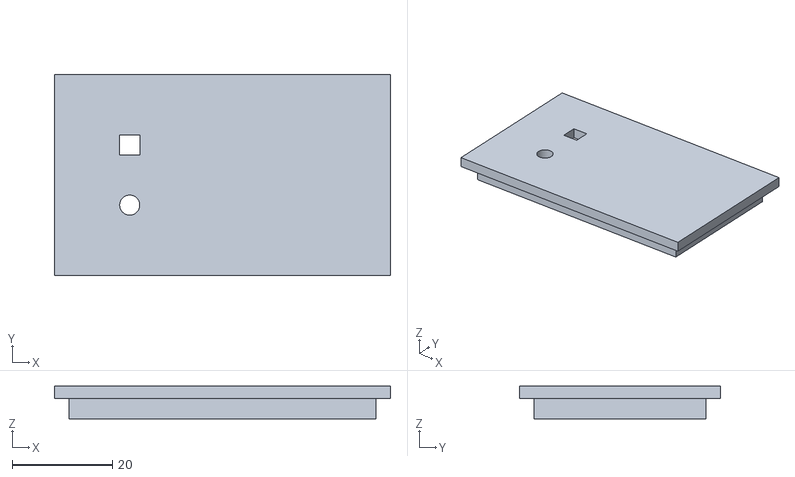
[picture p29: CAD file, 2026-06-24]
device-switch-electronic/assembly/switch-enclosure-lid.stl
67.0 x 40.0 x 6.50

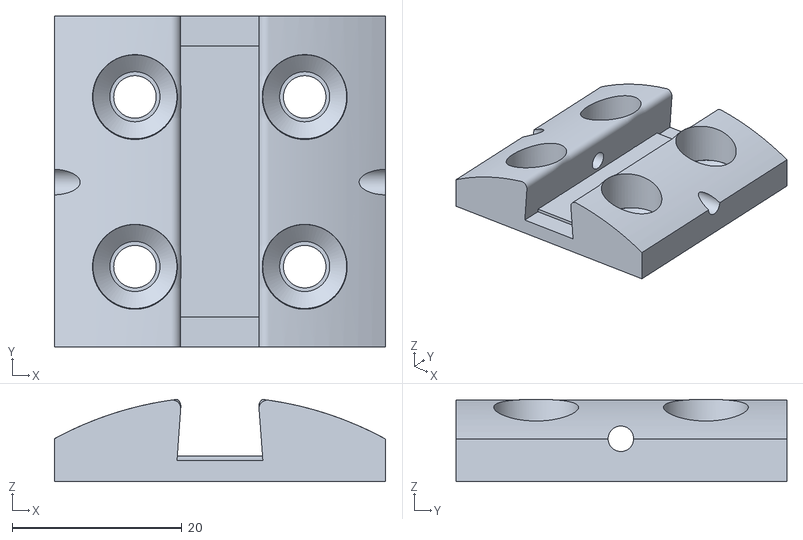
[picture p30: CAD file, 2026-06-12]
device-pro-acoustic/hardware/3d-print/bFaaaP_FF-FF.stl
39.1 x 39.0 x 9.71

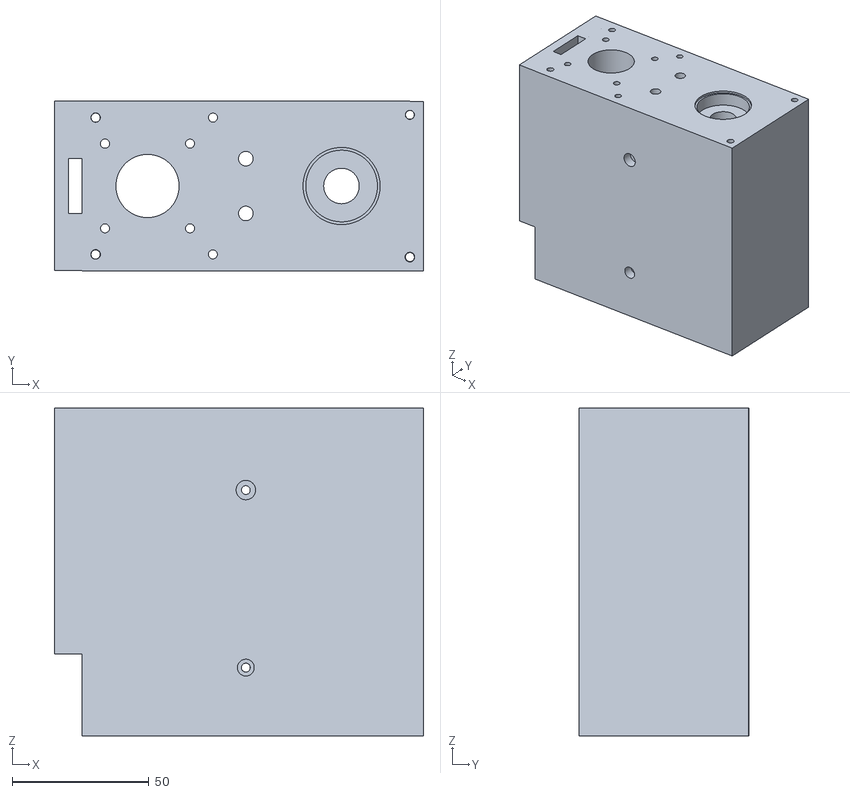
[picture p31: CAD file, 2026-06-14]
device-pro-acoustic/hardware/3d-print/from-discord-2025/bFaaaP_AA-A.stl
135.1 x 62.1 x 120.0

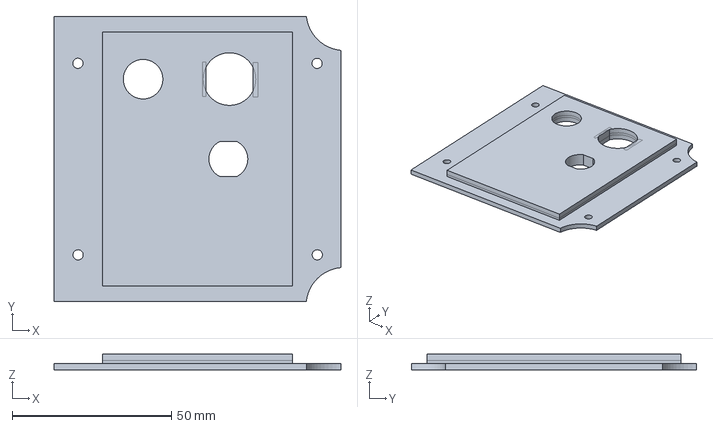
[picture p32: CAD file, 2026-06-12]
device-pro-acoustic/hardware/cad/bFaaaP_DD.FCStd
90.0 x 89.5 x 5.00 mm

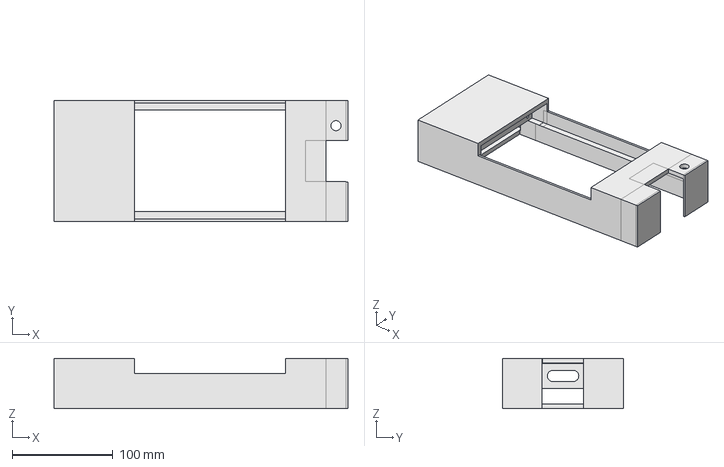
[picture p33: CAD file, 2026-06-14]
device-pro-acoustic/hardware/cad/from-discord-2025/bfaaap_base_plus_airjack.FCStd
292.0 x 120.1 x 50.1 mm

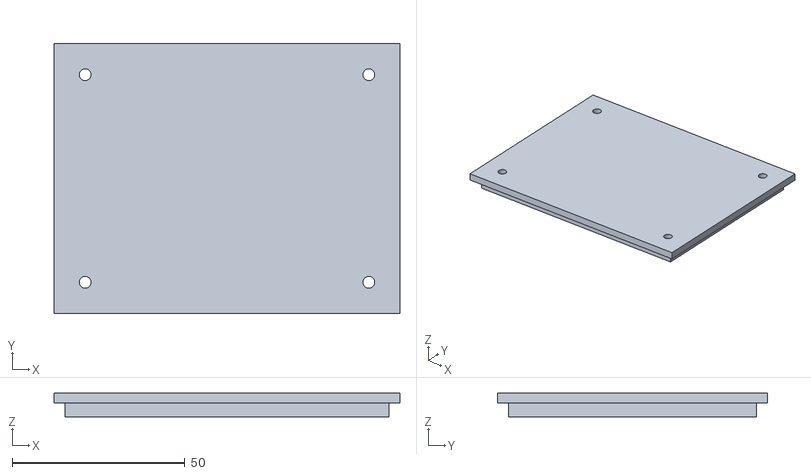
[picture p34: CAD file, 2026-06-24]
device-pro-acoustic/hardware/reference-design/pro-ebox-lid.stl
100.0 x 78.0 x 6.80

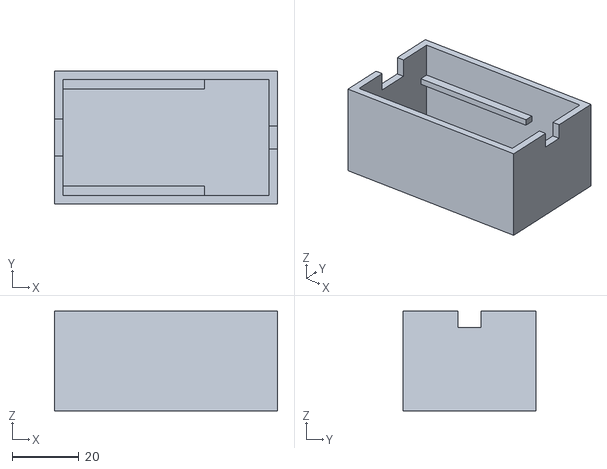
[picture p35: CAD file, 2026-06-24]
device-switch-electronic/assembly/switch-enclosure-base.stl
67.0 x 40.0 x 30.0

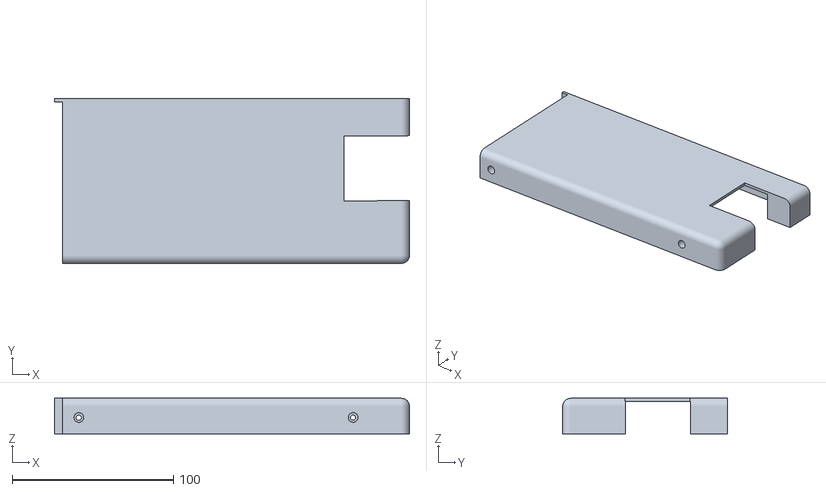
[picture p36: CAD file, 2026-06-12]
device-pro-acoustic/hardware/3d-print/bfaaap_G-G.stl
220.0 x 102.0 x 22.0

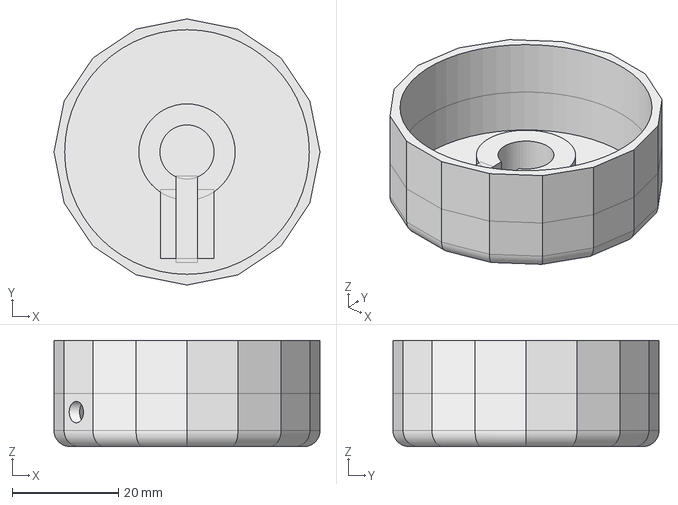
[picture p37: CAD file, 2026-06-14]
device-pro-acoustic/hardware/cad/from-discord-2025/bfaaap_nob_b.FCStd
50.1 x 50.1 x 20.0 mm

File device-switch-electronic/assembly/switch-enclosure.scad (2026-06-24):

// =====================================================================
//  bFaaaP Switch — simple 3D-printable enclosure   (AI DRAFT DESIGN)
// ---------------------------------------------------------------------
//  Parametric case for: Adafruit ItsyBitsy nRF52840 + 2x AA holder +
//  RU1J002YN low-side MOSFET. Two parts: base tray + lid.
//  Cable & USB are U-notches in the base rim (closed by the lid -> no
//  support needed when printed open-side-down). Lid has a DotStar LED
//  window + a RESET access hole.
//
//  ⚠️ AI DRAFT DESIGN — generated by the bFaaaP project, UNTESTED.
//  Verify fit against your actual parts and adjust before printing.
//  License: CERN-OHL-W-2.0 (hardware) / CC BY 4.0 (drawing). Units: mm.
//  Open in OpenSCAD (free); set `part` then F6 -> Export STL.
// =====================================================================

part   = "both";   // "base", "lid", or "both"

// ---- main dimensions (edit to fit your parts) ----
L      = 67;   // external length
W      = 40;   // external width
T      = 2.5;  // wall thickness
FT     = 2.5;  // floor thickness
HB     = 30;   // base (tray) height
LT     = 2.5;  // lid plate thickness
LIP_H  = 4;    // lid locating-lip height
CL     = 0.4;  // lip clearance (loosen if too tight)
SHELF  = 17;   // board-shelf height above the floor
BX1    = 45;   // board shelf extends to this X

// feature positions
CABLE_W = 7;   CABLE_D = 5;     // cable notch (right wall)
USB_W   = 11;  USB_D   = 6;     // USB notch (left wall)
LED_X   = 15;  LED_S   = 4;     // LED window centre X, square side
RST_X   = 15;  RST_R   = 2;     // RESET hole centre X, radius
$fn     = 56;

module base() {
  difference() {
    cube([L, W, HB]);
    translate([T, T, FT])           cube([L - 2*T, W - 2*T, HB]);              // cavity (open top)
    translate([L - T - 1, (W-CABLE_W)/2, HB - CABLE_D]) cube([T + 2, CABLE_W, CABLE_D + 1]); // cable
    translate([-1, (W-USB_W)/2, HB - USB_D])            cube([T + 2, USB_W, USB_D + 1]);     // USB
  }
  // board shelf ledges (front + back inner walls)
  translate([T, T, SHELF])          cube([BX1 - T, 3, 2]);
  translate([T, W - T - 3, SHELF])  cube([BX1 - T, 3, 2]);
}

module lid() {
  difference() {
    union() {
      cube([L, W, LT]);
      translate([0, 0, -LIP_H]) difference() {                                 // locating lip frame
        translate([T + CL, T + CL, 0])
          cube([L - 2*(T + CL), W - 2*(T + CL), LIP_H]);
        translate([T + CL + 2, T + CL + 2, -1])
          cube([L - 2*(T + CL + 2), W - 2*(T + CL + 2), LIP_H + 2]);
      }
    }
    translate([LED_X - LED_S/2, W/2 + 6 - LED_S/2, -1]) cube([LED_S, LED_S, LT + 2]); // LED window
    translate([RST_X, W/2 - 6, -1]) cylinder(h = LT + 2, r = RST_R);                  // RESET hole
  }
}

if (part == "base" || part == "both") base();
if (part == "lid"  || part == "both") translate([0, W + 12, 0]) lid();

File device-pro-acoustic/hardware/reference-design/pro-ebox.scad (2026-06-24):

// =====================================================================
//  bFaaaP Pro — electronics-box enclosure   (AI DRAFT DESIGN)
// ---------------------------------------------------------------------
//  Simple, adaptable 2-part case for the Pro electronics: Raspberry Pi
//  Pico + nRF52840 BLE board + the MOSFET & terminal blocks. The motor
//  mount / lead-screw blocks / push-rod guide are SEPARATE motor-dependent
//  parts (not here). Cable & USB openings are U-notches in the base rim
//  (closed by the lid -> no support). 4 board standoffs + 4 lid screws.
//
//  AI DRAFT — generated by the bFaaaP project, UNTESTED. Check against your
//  actual boards/cables and adjust before printing.
//  License: CERN-OHL-W-2.0 (hardware) / CC BY 4.0. Units: mm. Open in OpenSCAD.
// =====================================================================

part = "both";   // "base", "lid", or "both"

L = 100;  W = 78;  HB = 36;     // external footprint + base height
T = 2.8;  FT = 2.8;             // wall + floor
LT = 2.8; LIP_H = 4; CL = 0.4;  // lid plate, locating lip, clearance
STAND_H = 6; STAND_D = 7; STAND_HOLE = 2.6;   // board standoffs (self-tap M3)
SCREW = 3.4;                    // lid corner screw clearance
INS = 9;                        // corner inset for standoffs / screws
$fn = 48;

corners = [[INS,INS],[L-INS,INS],[INS,W-INS],[L-INS,W-INS]];

module base() {
  difference() {
    cube([L, W, HB]);
    translate([T, T, FT])                 cube([L-2*T, W-2*T, HB]);            // cavity
    translate([-1, W/2-7, HB-8])          cube([T+2, 14, 9]);                  // power in (left)
    translate([L-T-1, W/2-7, HB-8])       cube([T+2, 14, 9]);                  // motor (right)
    translate([L/2-6, -1, HB-7])          cube([12, T+2, 8]);                  // hand controller (front)
    translate([30-6, W-T-1, HB-6])        cube([12, T+2, 7]);                  // USB slot A (back)
    translate([70-6, W-T-1, HB-6])        cube([12, T+2, 7]);                  // USB slot B (back)
  }
  for (c = corners) translate([c[0], c[1], FT])                               // standoffs
    difference() {
      cylinder(h=STAND_H, d=STAND_D);
      translate([0,0,-1]) cylinder(h=STAND_H+2, d=STAND_HOLE);
    }
}

module lid() {
  difference() {
    union() {
      cube([L, W, LT]);
      translate([0,0,-LIP_H]) difference() {                                   // locating lip
        translate([T+CL,T+CL,0])     cube([L-2*(T+CL), W-2*(T+CL), LIP_H]);
        translate([T+CL+2,T+CL+2,-1])cube([L-2*(T+CL+2), W-2*(T+CL+2), LIP_H+2]);
      }
    }
    for (c = corners) translate([c[0], c[1], -1]) cylinder(h=LT+2, d=SCREW);   // screw holes
  }
}

if (part == "base" || part == "both") base();
if (part == "lid"  || part == "both") translate([0, W+12, 0]) lid();

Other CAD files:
device-pro-acoustic/hardware/3d-print/from-discord-2025/bFaaaP_FF-FF.stl
device-pro-acoustic/hardware/cad/bFaaaP_FF.FCStd
device-pro-acoustic/hardware/3d-print/bFaaaP_BB_b-bFaaaP_BB.stl
device-pro-acoustic/hardware/3d-print/from-discord-2025/bFaaaP_E_a-E.stl
device-pro-acoustic/hardware/3d-print/10mm_dai-a.3mf
device-pro-acoustic/hardware/3d-print/10mm_dai-a.stl
device-pro-acoustic/hardware/3d-print/bFaaaP_AA_a-A.stl
device-pro-acoustic/hardware/3d-print/bFaaaP_AA_b-A.stl
device-pro-acoustic/hardware/3d-print/bFaaaP_BB_b-slide.stl
device-pro-acoustic/hardware/3d-print/bFaaaP_BB_b-tension.stl
device-pro-acoustic/hardware/3d-print/bFaaaP_CC_DD-CC.stl
device-pro-acoustic/hardware/3d-print/bFaaaP_DD_a-E.3mf
device-pro-acoustic/hardware/3d-print/bFaaaP_DD_a-E.stl
device-pro-acoustic/hardware/3d-print/bFaaaP_PCB_dai-Body.stl
device-pro-acoustic/hardware/3d-print/bFaaaP_PW_BOX-PW_back.stl
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

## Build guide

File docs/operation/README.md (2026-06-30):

# Operating bFaaaP

> 🌐 **English** · [日本語](../../i18n/ja/docs/operation/README.md) · [Deutsch](../../i18n/de/docs/operation/README.md)

A short guide to using the system day to day. (Pro / acoustic line; the Switch
line operates the same from the app's side.)

> **Watch the real setup**: the developer demonstrates installation at
> **25:01–28:32** in <https://www.youtube.com/watch?v=V3cXeNW9jXY>. The steps below
> follow that demonstration.

## Setup, as demonstrated (Pro)

1. Place the (lightweight) device so its **drive axis lines up with the sustain
   (damper) pedal**.
2. Put the **airback** under a **neighbouring pedal** and **inflate it with the
   pump** — it presses that pedal down from below and **absorbs the reaction
   force**, so driving the sustain pedal can't push the device back. **Check the
   unit no longer moves.**
3. The drive travel is then set: the **lower end is found automatically**, and
   the **upper end is set with the slider** on the hand controller.
4. Mount the iPhone facing the player and start the app (below). Tilting the head
   down sustains; returning releases.

## One‑time / each session

1. **Place & anchor the device** at the pedals. In the reference setup the Pro
   unit sits on a **wooden board** in front of the grand‑piano **pedal lyre**, with
   its actuator over the **sustain (right) pedal**; the **airback** (blue air bag)
   sits beside it. Inflate the airback with the hand pump until the unit is firmly
   clamped and cannot move. See
   [`../../device-pro-acoustic/hardware/airback/`](../../device-pro-acoustic/hardware/airback/).
2. **Mount the iPhone/iPad** on the music desk (or a stand) **facing the player's
   face**, so the front TrueDepth camera can track the head. (In the reference
   videos a phone is propped on the piano's music desk at the player's eye level.)
3. Use the hand controller **slider** to set the **top position / travel limit**
   of the driving part so the pedal is pressed the right amount.
4. **Power on** the device. It advertises over BLE as `bFaaaPSwitch_1`
   (or `_2`…`_4` if you set another channel).

## In the app

1. Open the app and grant **Camera** and **Bluetooth** permissions.
2. **Select the channel** matching your device (1–4). The app connects only to a
   `bFaaaPSwitch_n` device.
3. Hold the iPhone/iPad so the **front (TrueDepth) camera sees your face**.
4. **Individualized pre‑setting (one‑time per player — important).** In the app,
   set the **threshold start‑point (offset)** so a normal head pose means
   "pedal up", and set the **multiplier** for how much head tilt reaches a full
   pedal. **Each player presets these to their own comfortable range and speed of
   head motion**, and the app stores the preset. This is what makes the control
   **individualized**: the same device serves an able‑footed adult, a child, and a
   player with restricted head motion — e.g. someone whose neck movement is limited
   picks a **small offset and a large multiplier**. Redo this preset for each new
   player or sitting position.
5. **Tilt your head** to engage the sustain; return to neutral to release. The
   screen is **white at rest and turns red when engaged**, so you can see the
   state at a glance. (Same app and behaviour for both Pro and Switch.)

## Tips

- Keep the screen on — the app disables auto‑lock while playing.
- If the device disconnects, the app re‑scans and reconnects automatically.
- The on‑type / off‑type setting flips whether a tilt means "sustain on" or
  "sustain off"; pick whichever feels natural.

## Signal reference

| App sends | Result |
|---|---|
| `iNN` (every 100 ms) | target pedal amount `00`–`99` |
| `N` / `F` | engage / release |
| channel / type commands | configure the device |

Full protocol: [`../architecture/`](../architecture/).

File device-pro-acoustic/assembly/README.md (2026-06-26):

# Assembly guide & Bill of Materials

> The BOM below is reconstructed from the project's internal cost estimate
> (`bFaaaP_pro原価概算`). It reflects the **IQ‑motor generation**; see the notes
> for the stepper migration and EOL replacements
> ([`../HARDWARE-AVAILABILITY.md`](../HARDWARE-AVAILABILITY.md)).
> Step‑by‑step assembly photos/figures are still **TODO** (to be provided by the
> hardware author).

## Bill of materials

Approximate prices are JPY at build time (suppliers: 秋月電子 = Akizuki, アマゾン = Amazon,
Crowd Supply). Total ≈ **¥56,700** + power supply (¥2,000–7,600).

### Drive & motion

| Part | Spec | Notes |
|---|---|---|
| **Motor** | **IQ‑FORTIQ‑M42BLS‑100** (IQ motor, 100 W) | Crowd Supply, ≈¥33,000. **EOL** → planned successor = a **NEMA17 ("17‑type") stepper** of the **same size** (so it fits the existing frame), driven **STEP/DIR** (see availability doc) |
| Lead screw + nut | **T10**, **lead 16 mm/rev**, **length 150 mm** | converts rotation → linear pedal push |
| Timing belt | **GT-2‑262** | motor → lead screw |
| Timing pulleys | **T60**, 5 mm (motor) & 10 mm (screw) bore | 1:1 |
| Bearings | flanged + thrust + collar | lead‑screw support |
| **Push‑rod assembly** | a **2040 extrusion, L = 75 mm**, with a **15 mm‑thick PLA** part on top (holds the lead‑screw **nut**) and a **PLA** part at the bottom (holds a **hard‑rubber** tip that contacts the pedal); **total length 115 mm** | the carriage that the nut drives down onto the sustain pedal |
| **Drive‑motor cooling fan** | small fan on **+5 V** (from the box) | cools the drive motor |

### Frame & enclosure

| Part | Spec |
|---|---|
| Aluminium extrusion | **4040** (60 mm), **2040** (200 mm), **2080** (200 mm) |
| T‑slot / brackets | 20 mm M3 T‑slot, 2020 corner brackets |
| 3D‑printed parts | **PLA+** filament (see [`../hardware/3d-print/`](../hardware/3d-print/)) |

### Anchoring (airback)

| Part | Spec | Notes |
|---|---|---|
| **Air jack (airback)** | **WINBAG** air jack — 160 × 150 mm, up to 50 mm, **135 kg** | off-the-shelf inflatable anchor under a neighbouring pedal — see [`../hardware/airback/`](../hardware/airback/) for specs + where to buy |
| **Air pump** | a small **electric air pump inside the electronics box** — driven by the **2SK4017** MOSFET on **GP12**, switched by the panel **PUMP SW** | inflates the air jack through an **air tube**. The built device does **not** use the WINBAG's hand squeeze-bulb |
| Pneumatic tube | **air tube** from the box's pump to the WINBAG (+ the WINBAG's own bleed valve) | carries air from the box to the airback |

### Electronics

| Part | Spec | Notes |
|---|---|---|
| **Main board** | **Raspberry Pi Pico** (RP2040) | motor/pump/sensor control |
| **BLE board** | **Akizuki `AE-NRF52840`** (g117484); **Adafruit Feather nRF52840** = compatible alternative | Bluetooth ↔ UART bridge to the Pico on **GP0/GP1**. *Not* the ItsyBitsy/DotStar — that's the **Switch** line's board (confirmed by Taguchi, 2026‑06‑24) |
| **Pump driver** | **n‑MOSFET 2SK4017** | GP12 → the **electric air pump** (in the box) |
| **Pressure sensor** | **HX711** (used as air‑pressure sensor) | air‑jack pressure feedback |
| **Upper‑limit input** | **slide potentiometer ("slide volume")** ✅ | sets the travel top; read on Pico **ADC0/GP26** (confirmed by the device co‑author) |
| **Hand controller link** | LAN connector + cable (RJ45) — *legacy* | listed in the original BOM but **currently unused** (per the device co‑author); the pot + switch are wired in directly |
| Misc | 8‑pin connector, tact switch, power switch, LED, resistors, capacitors, wire | |

### Power

| Part | Spec |
|---|---|
| PSU | **AC100 → DC24V** switching module (≈¥2,000; +5 V variants ≈¥2,600 / ¥7,600) |

> Migration note: the **planned successor** to the EOL IQ motor is a **NEMA17 ("17‑type")
> stepper of the same size** (so it reuses the existing frame), driven **STEP/DIR** (the team
> prototyped with a **DRV8825** driver; the stepper firmware `v052B` is still in development —
> a buildable version is **not yet finalised**). For currently‑available motor/driver/board
> choices and how they change the firmware, see [`../HARDWARE-AVAILABILITY.md`](../HARDWARE-AVAILABILITY.md).

## Build steps (outline)

1. Cut the aluminium extrusions and **print the parts** (`hardware/3d-print/`); assemble the frame.
2. Build the **vertical** drivetrain: **motor (offset) → GT-2‑262 belt over T60/T60 pulleys (1:1) →
   vertical T10 lead screw → carriage/nut → push‑rod** (presses straight down), with its bearings.
3. Fit the **air jack** under a neighbouring pedal and run the **air tube** from the box's **electric
   pump** (GP12 / 2SK4017, panel PUMP SW) to the WINBAG.
4. Wire the **Pico ↔ nRF52 board ↔ motor driver ↔ HX711 ↔ slider (via RJ45) ↔ 24 V PSU**
   (see [`../firmware/CODE-STRUCTURE.md`](../firmware/CODE-STRUCTURE.md) and the wiring notes).
5. **Flash** both boards ([`../../docs/toolchain/`](../../docs/toolchain/)).
6. Install the iOS app, pair, run the boot calibration (air‑jack → lower limit → slider), and test.

> TODO (from the hardware author): a clean single‑sheet wiring/schematic, fastener
> list, exploded assembly figures, and the stepper‑generation part numbers.

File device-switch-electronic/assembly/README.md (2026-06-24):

# Switch — enclosure & assembly (packaging)

> ⚠️ **AI DRAFT DESIGN.** This enclosure was drafted by the bFaaaP project (AI-assisted)
> from the device's known internals — it is **untested**. Treat the dimensions as a
> starting point: check them against your actual ItsyBitsy board, AA holder and cable,
> and adjust before printing. The electrical design (firmware + the RU1J002YN switch)
> is the verified part; this case is just convenient packaging.

A simple, adaptable two-part case that holds the **whole Switch**: an
**Adafruit ItsyBitsy nRF52840**, a **2× AA holder**, and the **RU1J002YN** sustain
switch (see [`../hardware/`](../hardware/)).

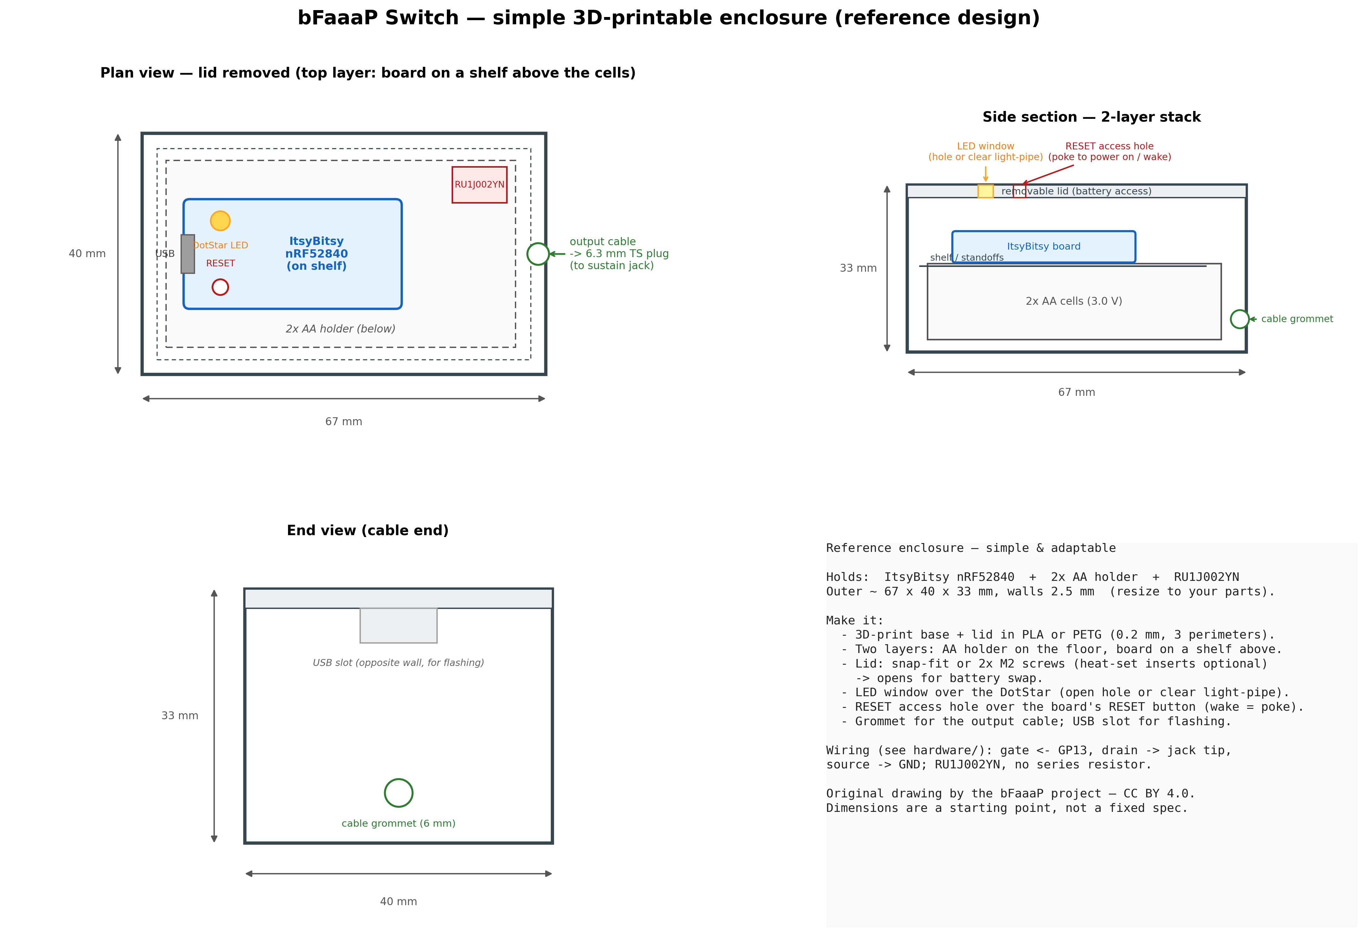
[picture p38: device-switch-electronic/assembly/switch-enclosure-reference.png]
Switch enclosure reference drawing


## What's here

| File | What it is |
|---|---|
| [`switch-enclosure.scad`](switch-enclosure.scad) | **Parametric source** (OpenSCAD) — edit the dimensions, then export STL. **Start here to adapt it.** |
| [`switch-enclosure-base.stl`](switch-enclosure-base.stl) | Ready-to-slice **base tray** (open-top; cable + USB notches; board shelf ledges). |
| [`switch-enclosure-lid.stl`](switch-enclosure-lid.stl) | Ready-to-slice **lid** (locating lip + DotStar LED window + RESET access hole). |
| `switch-enclosure-reference.png` | The dimensioned reference drawing above. |

> The STLs were generated from the `.scad` parameters and are **watertight/manifold**.
> To change anything (board size, AA-holder size, hole positions), edit the `.scad`
> in [OpenSCAD](https://openscad.org) (free) and re-export — that's the adaptable path.

## Design (≈ 67 × 40 × 33 mm outer, 2.5 mm walls)

- **Two layers:** the 2× AA holder sits on the floor; the ItsyBitsy board rests on
  two **shelf ledges** above it — keeps the footprint small.
- **Lid** nests in with a locating lip and lifts off for **battery swaps** (2× AA are
  replaceable). Hold it with a snap fit or **2× M2 screws** (heat-set inserts optional).
- **DotStar LED window** over the board's RGB LED (open hole, or drop in a clear
  light-pipe / hot-glue lens).
- **RESET access hole** over the board's RESET button — this is how you **power on /
  wake** the Switch (there is no separate power button; poke RESET).
- **Cable grommet / U-notch** for the output lead to the **6.3 mm TS plug**.
- **USB slot** lined up with the board's USB connector for **flashing**.

## Print settings (suggested)

- Material **PLA** or **PETG** (PETG if it may sit in a warm car/venue).
- 0.2 mm layers, **3 perimeters**, 15–20 % infill.
- Orientation: print both parts **open-side-down** — no supports needed (the notches
  are bridged by the lid, the holes are small).

## Assembly

1. Print `base` and `lid`. Test-fit the lid lip; loosen `CL` in the `.scad` if tight.
2. Drop the **2× AA holder** onto the floor (double-sided tape or a dab of hot glue).
3. Wire the **RU1J002YN** per [`../hardware/`](../hardware/): gate → `GP13`,
   drain → the sustain-jack lead, source → GND/battery −. Keep it on a tiny stub
   board or heat-shrink it inline near the cable exit.
4. Seat the **ItsyBitsy** on the shelf ledges, USB facing the USB slot, DotStar under
   the LED window, RESET under the RESET hole. Route the output cable through the notch.
5. Flash the firmware ([`../firmware/`](../firmware/)) via the USB slot, fit the lid.

---
**Credits:** original design by the **bFaaaP project** (AI-assisted draft). Hardware
layer **CERN-OHL-W-2.0**; the drawing is **CC BY 4.0**. Generators kept in the
project's private tooling — only the outputs (`.scad`, `.stl`, `.png`) are committed.

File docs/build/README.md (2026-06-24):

# 🔧 Build it yourself

> 🌐 **English** · [日本語](../../i18n/ja/docs/build/README.md) · [Deutsch](../../i18n/de/docs/build/README.md)

bFaaaP is open source — you can build the **iOS app** and either device. This hub points to
each build track. New to the terms? See the [glossary](../GLOSSARY.md) and
[how it works](../how-it-works.md) first. Want the file behind any part/figure/code? see the
[source map](../SOURCE-MAP.md). Stuck? ask in [AI‑assisted Support](../ai-support.md).

Pro for acoustic pianos, Switch for digital pianos

## Choose your track

| Track | You need | Step‑by‑step guide | Detailed reference |
|---|---|---|---|
| 📱 **iOS app** (required for both devices) | a Mac + Xcode + an iPhone/iPad with Face ID | **[→ Build the iOS app](ios.md)** | [`../../ios-app/`](../../ios-app/) |
| 🎹 **Pro** (acoustic piano) | 3D printer, soldering, the motor + boards | **[→ Build the Pro](pro.md)** | [`../../device-pro-acoustic/`](../../device-pro-acoustic/) |
| 🎛️ **Switch** (digital piano) | the boards + a pedal‑jack connection | **[→ Build the Switch](switch.md)** | [`../../device-switch-electronic/`](../../device-switch-electronic/) |

## The big picture
```
[ Build & install the iOS app ]  ──┐
                                   ├─▶  pair over Bluetooth  ──▶  play foot‑free
[ Build a device: Pro or Switch ] ─┘
```

1. **Build the app** (everyone) — set your own signing team & bundle ID, install on your device.
2. **Build a device** — Pro (motor + airback for acoustic) or Switch (electronic for digital).
3. **Flash the firmware** to the boards — see [`../toolchain/`](../toolchain/).
4. **Pair, calibrate, and play** — see [`../operation/`](../operation/) and [`../user-manual/`](../user-manual/).

> 🚧 **Draft:** the step‑by‑step guides above are first drafts — a few exact pinouts and
> mechanical dimensions are still being filled in from the makers (Narusawa / Taguchi). The
> videos — especially the **[Pro setup walkthrough](https://www.youtube.com/watch?v=_9YopbCYTmI)**
> — show the real process. See the full [video guide](../videos/).

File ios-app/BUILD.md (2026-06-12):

# Building the iOS app

> 日本語・ドイツ語版は後日 `i18n/` 配下に追加予定（English first）.

The full Xcode project is in [`src/`](src/). It has been sanitized for public
use: **signing team is blank** and the **bundle identifier is a placeholder**.
Another Apple Developer can build it by adding their own team and ID.

## Requirements

- macOS with a recent **Xcode**.
- An **Apple Developer account** (free account is enough to run on your own device).
- A test device with a **TrueDepth front camera** (Face ID class). The iOS
  **Simulator cannot run face tracking**, so on‑device is required to actually use it.

## Steps

1. Open `src/bFaaaPSwitch1.xcodeproj` in Xcode.
2. Select the **bFaaaPSwitch1** target → **Signing & Capabilities**:
   - Set **Team** to your own (it is intentionally empty in this repo).
   - Change **Bundle Identifier** from the placeholder `com.example.bfaaap`
     to one you own, e.g. `com.yourname.bfaaap`.
   - Signing is **Automatic**; Xcode will create a development profile for you.
3. Connect a TrueDepth device, select it as the run destination.
4. **Build & Run** (⌘R). Grant the **Camera** and **Bluetooth** permissions when prompted.
5. Pair with a powered‑on bFaaaP device (advertised as `bFaaaPSwitch_1`) and play.

## What was changed for publication

| Setting | In this repo | Original (private) |
|---|---|---|
| `DEVELOPMENT_TEAM` | empty (`""`) | a specific team ID |
| `PRODUCT_BUNDLE_IDENTIFIER` | `com.example.bfaaap` | the author's reverse‑DNS ID |
| `xcuserdata`, signing certs, profiles, API keys | removed / never included | — |

Author attribution in source headers is intentionally kept.

## Notes

- Deployment target is **iOS 14.5**; the project builds cleanly against current
  iOS SDKs (verified on Xcode 26 / iOS 26 SDK).
- iCloud and Push capabilities were removed (the app does not use them); only
  Camera and Bluetooth permissions are required (declared in `Info.plist`).
- See [`CODE-STRUCTURE.md`](CODE-STRUCTURE.md) and
  [`DESIGN-HIGHLIGHTS.md`](DESIGN-HIGHLIGHTS.md) to understand the code.

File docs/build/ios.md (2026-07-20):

# 📱 Build the **iOS app**

> 🌐 **English** · [日本語](../../i18n/ja/docs/build/ios.md) · [Deutsch](../../i18n/de/docs/build/ios.md)



The app is required for **both** devices (Pro and Switch). It reads your head angle with Face‑ID
face tracking and sends pedal commands over Bluetooth. You can also just **download it for free** from
the App Store — building from source is for developers who want to customise or contribute.

> Reference: [`ios-app/BUILD.md`](../../ios-app/BUILD.md) · [`ios-app/CODE-STRUCTURE.md`](../../ios-app/CODE-STRUCTURE.md) · [`ios-app/DESIGN-HIGHLIGHTS.md`](../../ios-app/DESIGN-HIGHLIGHTS.md)

```
 1. Prereqs ─▶ 2. Open the project ─▶ 3. Set your signing ─▶ 4. Build to a device ─▶ 5. Permissions ─▶ 6. Pair & tune
```

## Step 0 — What you need
- A **Mac** with **Xcode 15+**
- An **iPhone/iPad with a TrueDepth (Face ID) camera** — required for head tracking (the Simulator can't do it)
- A free **Apple ID** is enough to install on your own device (a paid Apple Developer account is only needed to distribute)

## Step 1 — Get the source
Clone the repo and open the Xcode project:
```sh
git clone https://github.com/bfaaap/bfaaap_opensource.git
open bfaaap_opensource/ios-app/src/bFaaaPSwitch1.xcodeproj
```

## Step 2 — Set your signing
In Xcode: select the project → **Signing & Capabilities** → choose **your Team** and change the
**Bundle Identifier** to something unique (the published one is sanitised to `com.example.bfaaap`).

## Step 3 — Build & run on your device
Connect the iPhone/iPad by USB, select it as the run destination, and press **Run** (▶). On
first launch, **allow Camera (face tracking)** and **Bluetooth** when prompted.

## Step 4 — Pair & tune
Turn on the bFaaaP device, connect from the app, and set your **threshold (offset)** (how far to
tilt) and **multiplier** (sensitivity); together these two presets give your **response speed** —
how fast the pedal follows your head. See the BLE flow in [`ios-app/BLE-CONNECTION-FLOW.md`](../../ios-app/BLE-CONNECTION-FLOW.md)
and operation in [`docs/operation/`](../operation/).

> Prefer not to build? Get it **free** on the **App Store**: <https://apps.apple.com/app/id1545866059>

---
→ [Build hub](README.md) · [Pro build](pro.md) · [Switch build](switch.md)

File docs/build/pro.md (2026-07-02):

# 🎹 Build the **Pro** (acoustic piano)

> 🌐 **English** · [日本語](../../i18n/ja/docs/build/pro.md) · [Deutsch](../../i18n/de/docs/build/pro.md)

Step‑by‑step guide to build the Pro device — a small motor that presses an acoustic piano's
sustain pedal, anchored by an *airback* air‑cushion (nothing is screwed to the piano). New to
the terms? see the [glossary](../GLOSSARY.md). Stuck? [ask in AI‑assisted Support](../ai-support.md).

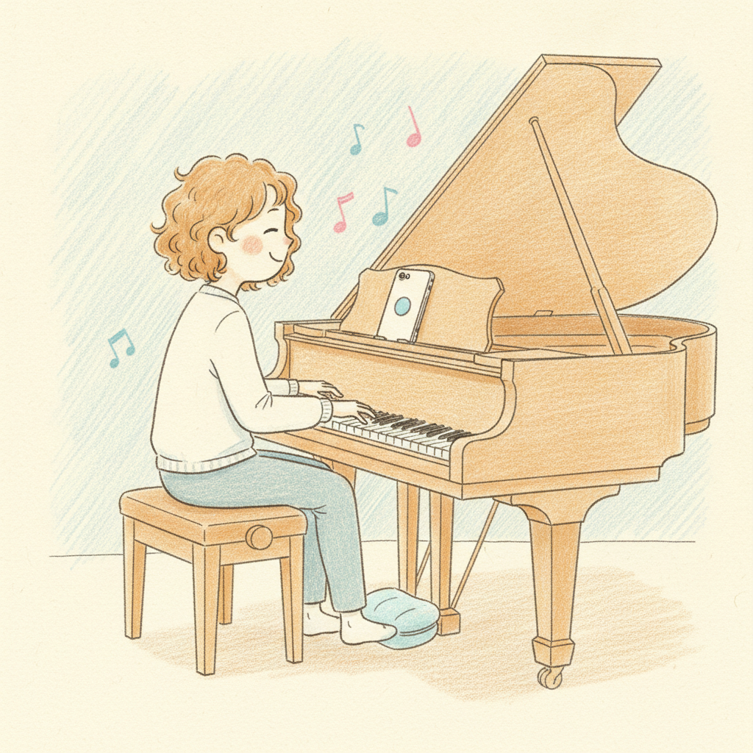
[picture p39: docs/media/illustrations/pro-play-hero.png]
A pianist plays a grand piano foot‑free: a phone on the music stand reads their head tilt while a small device and air cushion press the sustain pedal

<sub>What you're building toward: foot‑free pedalling on an unmodified grand. Illustration: AI‑generated (Saki Shiokawa style) © Shishido &amp; Associates.</sub>

> 🚧 **Draft.** The **electrical schematic** (Taguchi) and the **mechanical layout** (H. Narusawa's
> build sketch) are now confirmed and reflected below; what's still being finalised is the exact
> **stepper successor's buildable firmware** (the planned motor is a same‑size **NEMA17**, STEP/DIR; the original is EOL) and the **final printed‑part variant**.
> Watch the **[Pro setup walkthrough video](https://www.youtube.com/watch?v=_9YopbCYTmI)** to see it for real.

```
 1. Print parts ─▶ 2. Get electronics ─▶ 3. Assemble the drive ─▶ 4. Wire the boards
       ─▶ 5. Flash firmware ─▶ 6. Mount + airback ─▶ 7. Set force & calibrate ─▶ 8. Pair & play
```

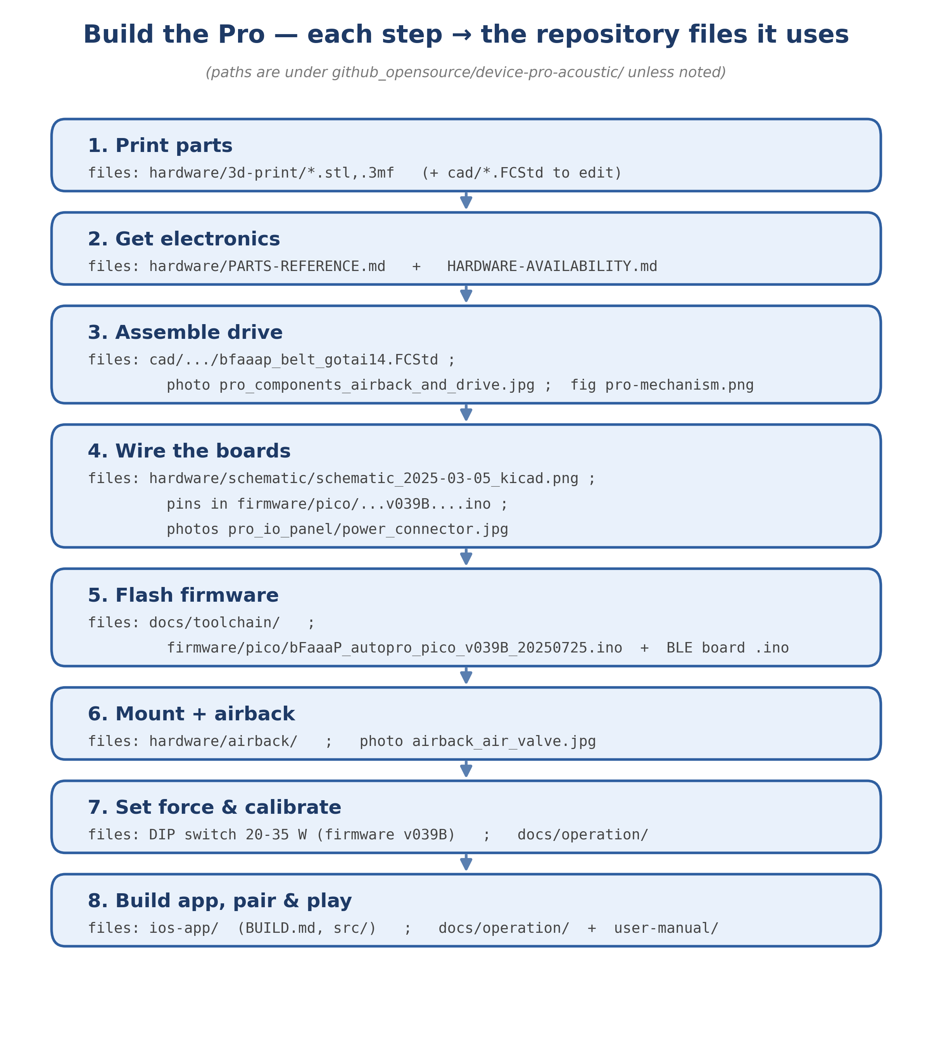
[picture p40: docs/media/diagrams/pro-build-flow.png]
Pro build steps and the repository files each step uses

<sub>Every step maps to specific repo files — full index in the [source map](../SOURCE-MAP.md).</sub>

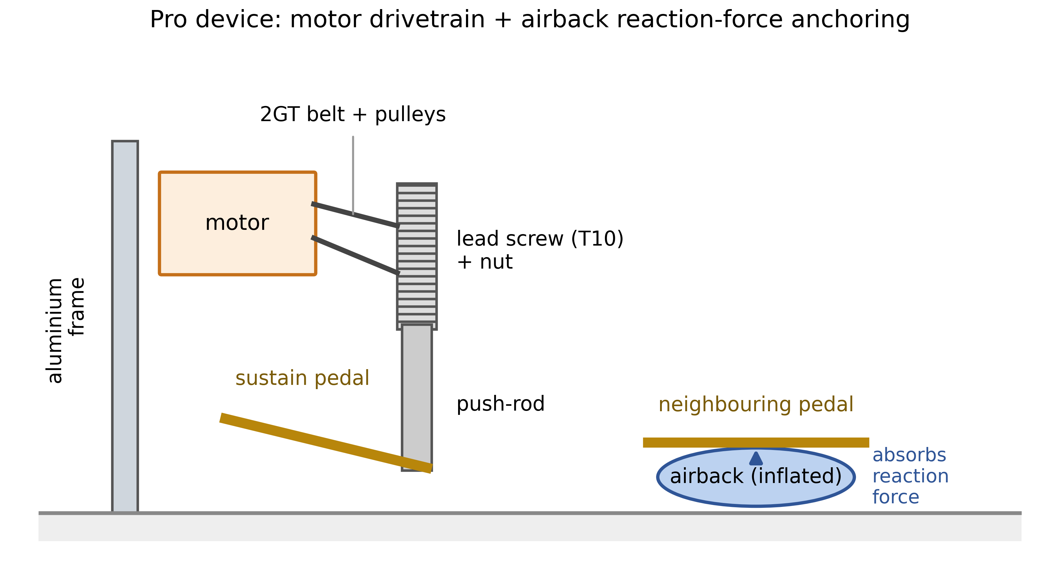
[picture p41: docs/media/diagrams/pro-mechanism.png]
Pro drive mechanism


The drive is a **vertical column**: a motor sits **beside** the screw and the **push‑rod presses
straight down** on the sustain pedal. For the full picture see the **[reference design](../../device-pro-acoustic/hardware/reference-design/)**
— a [system‑architecture diagram](../../device-pro-acoustic/hardware/reference-design/pro-architecture.png)
and a [mechanical‑layout diagram](../../device-pro-acoustic/hardware/reference-design/pro-mechanical-layout.png)
drawn after the working unit.

## Before you start — what you need
- A **3D printer** (≥240 mm bed helps) + **PLA+** filament
- Soldering iron, hookup wire, basic hand tools
- The **electronics** (see [`PARTS-REFERENCE.md`](../../device-pro-acoustic/hardware/PARTS-REFERENCE.md)):
  Raspberry Pi **Pico**, **nRF52840** BLE board, **IQ‑Fortiq** motor *(or the NEMA17 stepper successor)*,
  a **+5 V cooling fan**, **HX711**, **2SK4017** MOSFET, travel‑limit slider, **24 V PSU**
- Frame stock: **2040 + 2080 + 4040 aluminium extrusion**, a **GT-2‑262 belt** + **T60/T60 pulleys**,
  a **T10 lead screw** (**lead 16 mm/rev, 150 mm**), push‑rod
- The **airback** kit: a **WINBAG** air jack + a small **electric air pump** (housed in the box, driven
  from **GP12** via the **2SK4017** MOSFET and a panel **PUMP SW**) — the built device does **not** use the hand bulb
- An iPhone/iPad with **Face ID** + the [iOS app](ios.md)

## Step 1 — Print the mechanical parts
1. Open the `.stl` / `.3mf` files in [`hardware/3d-print/`](../../device-pro-acoustic/hardware/3d-print/) in a slicer (Bambu Studio, PrusaSlicer, OrcaSlicer…).
2. Use **PLA+**, **0.1–0.2 mm** tolerance; mind orientation (holes unsupported). See the [3D‑print notes](../../device-pro-acoustic/hardware/3d-print/README.md).
3. Print the frame parts, PCB mount, power box, push‑rod, and covers.

## Step 2 — Get the electronics
Order the parts from [`PARTS-REFERENCE.md`](../../device-pro-acoustic/hardware/PARTS-REFERENCE.md).
**Note:** the original IQ/Fortiq motor is **EOL** — the planned successor is a **NEMA17 ("17‑type") stepper of the same size** (so it reuses the frame), driven **STEP/DIR**. See [`HARDWARE-AVAILABILITY.md`](../../device-pro-acoustic/HARDWARE-AVAILABILITY.md).

## Step 3 — Assemble the drive unit
The drive is a **vertical column** (see the [reference design](../../device-pro-acoustic/hardware/reference-design/)):
1. Build the frame — a **vertical 2040 post** (L ≈ 200 mm) standing on a **2080 base** (L ≈ 200 mm).
2. Mount the **motor beside the screw** near the top and couple it with the **GT-2‑262 belt** over **two
   T60 pulleys (1:1)** — the belt only *offsets* the motor next to the screw, it is **not** a reduction.
3. Fit the **vertical T10 lead screw** (lead **16 mm/rev**) **down the left side of the 2040 post**; its
   **nut/carriage** runs down the frame and carries a **push‑rod** — a **2040 L=75 mm** piece with a
   **15 mm PLA** nut‑holder on top and a **PLA + hard‑rubber tip** below (~**115 mm**) — that presses
   **straight down** on the sustain pedal. Add the **+5 V cooling fan** on the motor.
4. House the boards in the printed **electronics box** (BLE + Pico) and the supply in the **power box (PW)**.

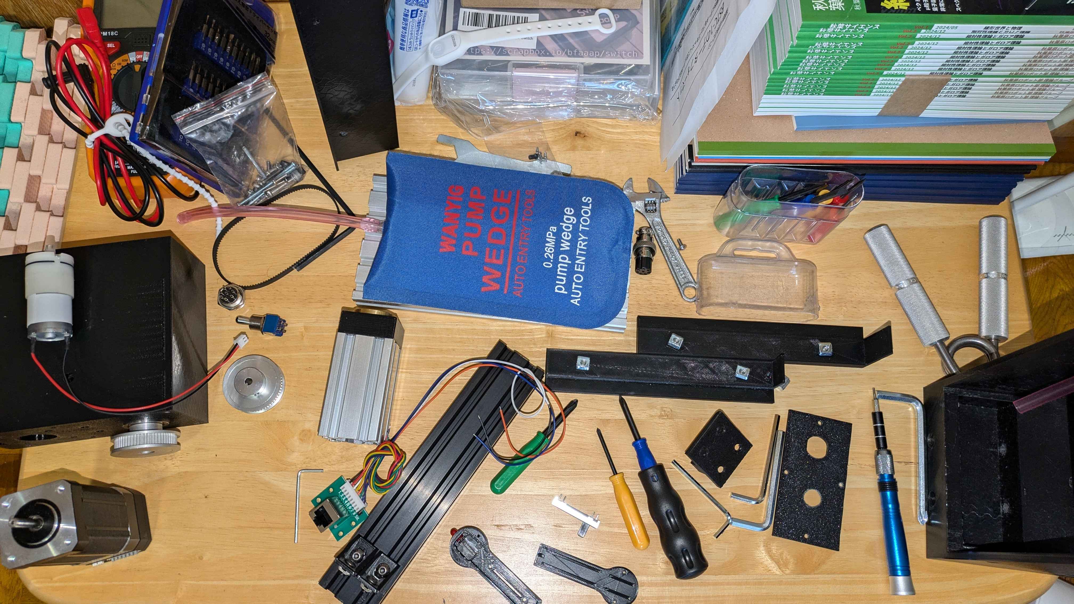
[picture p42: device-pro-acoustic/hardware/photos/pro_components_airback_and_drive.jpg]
Drive unit + airback components


## Step 4 — Wire the boards
Follow the schematic in [`hardware/schematic/`](../../device-pro-acoustic/hardware/schematic/).
Key connections (reference v039B):
- Motor serial → Pico **GP4 / GP5**
- **HX711** air‑pressure → **GP2 / GP3**; air pump on +5 V via **MOSFET → GP12**
- Travel‑limit slider → **ADC0 / GP26**; **DIP switch** for force/lift
- BLE board ↔ Pico over **UART (`Serial1`)**, common ground; **24 V** to the motor

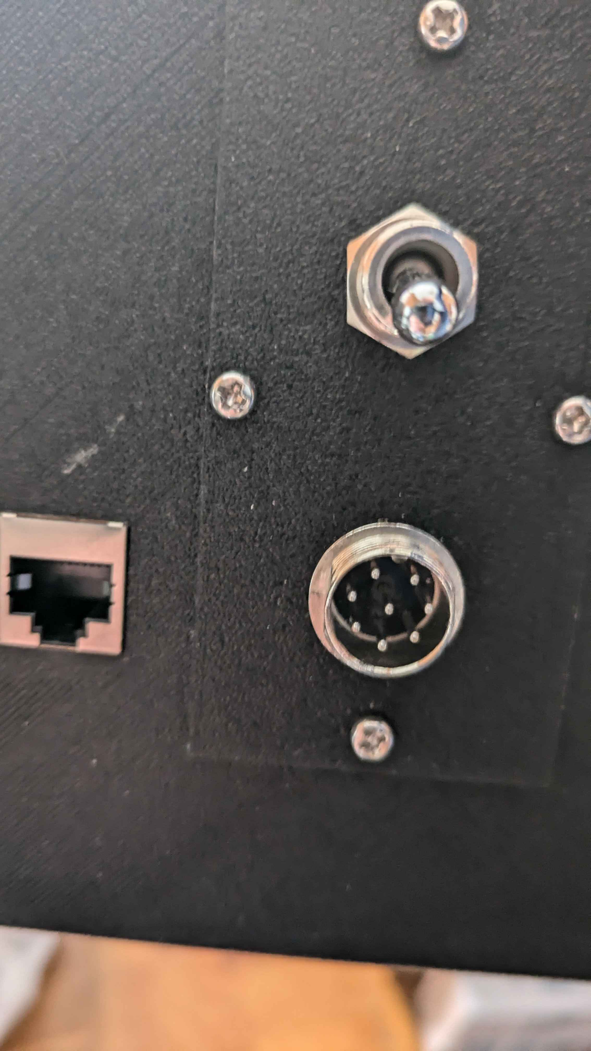
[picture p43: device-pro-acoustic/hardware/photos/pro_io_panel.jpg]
I/O panel

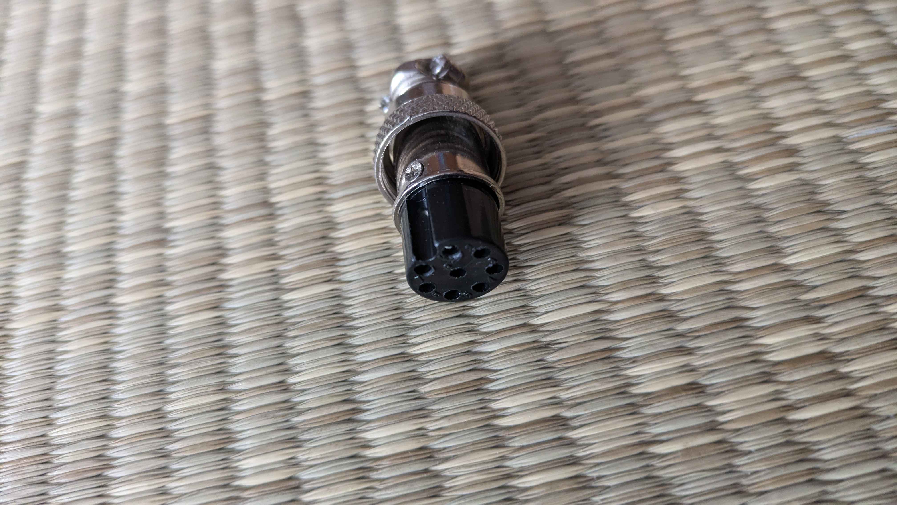
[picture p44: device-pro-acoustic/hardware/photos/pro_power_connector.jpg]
Power connector


> 🚧 *Exact pin/connector table is being confirmed with the makers — see
> [`DISCORD-FINDINGS.md`](../../device-pro-acoustic/DISCORD-FINDINGS.md) for confirmed details.*

## Step 5 — Flash the firmware
Flash **two boards** (full steps in [`docs/toolchain/`](../toolchain/)):
- **BLE board (nRF52):** install the Adafruit nRF52 support, double‑tap RESET, upload the BLE sketch.
- **Main board (Pico):** install the **arduino‑pico (Philhower)** core + HX711 + IQ library, hold **BOOTSEL**, upload **`bFaaaP_autopro_pico_v039B_…ino`** *(do **not** use the `v052B` stepper snapshot)*.

## Step 6 — Mount on the piano + airback
1. Place the drive so the push‑rod sits over the sustain pedal.
2. Anchor with the **airback**: run the **air tube** from the box's **electric pump** to the WINBAG and
   inflate it against a neighbouring pedal with the panel **PUMP SW**
   to absorb the reaction force — nothing touches the piano's finish. See
   [`hardware/airback/`](../../device-pro-acoustic/hardware/airback/).

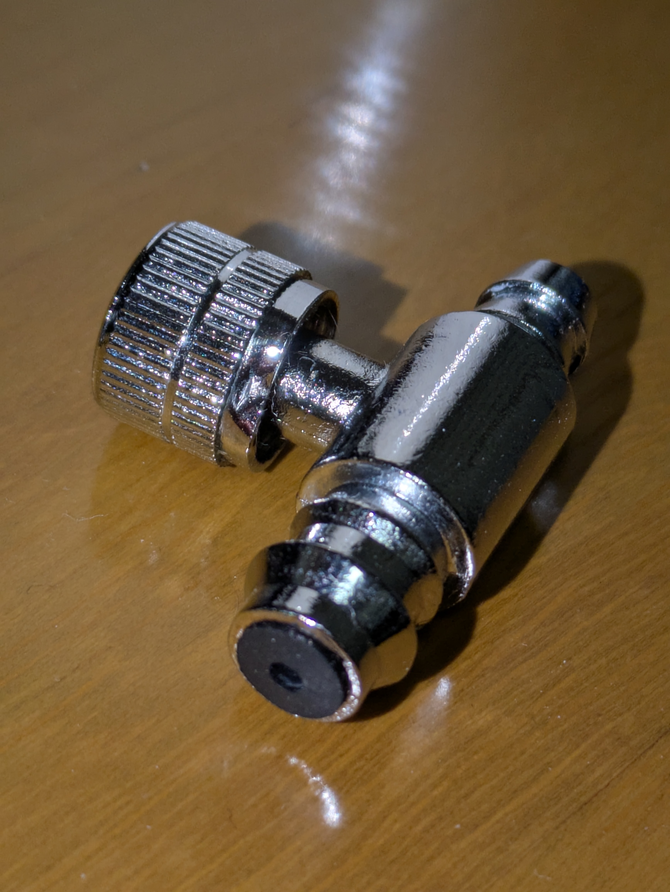
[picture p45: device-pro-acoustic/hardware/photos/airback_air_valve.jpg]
Airback air valve


## Step 7 — Set the pressing force & calibrate
- Set the **DIP switch** for pressing force **20–35 W** (1 W steps) and lift distance **5–20 mm**. Start in the low‑20s W and raise until the note sounds reliably (force is **power‑based**, piano‑dependent).
- Run the self‑calibration; watch the **Serial Monitor @ 115200**. A safety cap stops travel beyond ~50 mm.

## Step 8 — Pair the app & play
Build/install the [iOS app](ios.md), pair over Bluetooth, preset your **offset (threshold)** & **multiplier**
(together they fix how fast the pedal follows your head — see [how it works](../how-it-works.md)), calibrate
the head‑angle zero — and play. See [`docs/operation/`](../operation/).

## Mechanical BOM & CAD reference

The full reconstructed BOM (with prices, off‑the‑shelf parts) is in
[`assembly/README.md`](../../device-pro-acoustic/assembly/README.md). Below are the **3D‑printed
parts** with dimensions **measured from the CAD (BREP)** and the **editable source file** for each,
so you can print or modify any part.

> 🚧 The **final variant** of each part and the **fastener list** are being confirmed with the
> hardware author (H. Narusawa); the files below are the latest from the Discord CAD set.

| Printed part | Size (mm, L×W×H) | Editable CAD — `device-pro-acoustic/hardware/cad/from-discord-2025/` |
|---|---|---|
| New housing **AA** | 135×120×62 | `bFaaaP_AA.FCStd` (STL: `3d-print/from-discord-2025/bFaaaP_AA-A.stl`) |
| New housing **CC / DD** | 250×100×60 / 250×100×10 | STL `bFaaaP_CC-CC.stl` / `bFaaaP_DD-DD.stl` *(needs a large printer)* |
| Base + airjack | 292×124×50 | `bfaaap_base_plus_airjack2.FCStd` |
| Base + holder (osae) | 260×121×55 | `bfaaap_base_plus_osae_d.FCStd` |
| Air box | 200×125×35 | `bfaaap_airbox_a_2.FCStd` *(variants a/a‑1/a‑2/c exist)* |
| Slider (travel limit) | 243×132×25 | `bfaaap_slide2_20241028.FCStd` |
| DIP‑switch box | 60×30×6 | `bfaaap_dipsw_box_top_bot.FCStd` |
| Hand‑controller knobs | 50×50×10 / 50×50×20 | `bfaaap_nob_a.FCStd` / `bfaaap_nob_b.FCStd` |
| Push‑rod | (see CAD) | `bfaaap_push_poll.FCStd` |
| **Drive assembly (reference layout)** | 530×290×216 | `bfaaap_belt_gotai14.FCStd` |

Off‑the‑shelf mechanical parts (IQ motor → **NEMA17** successor, **T10 lead screw** lead **16 mm/rev** / 150 mm,
**GT-2‑262 belt**, **T60 pulleys** 5/10 mm bore, bearings, **2040 + 2080 + 4040** aluminium extrusion,
**WINBAG air jack** 160×150 mm / ≤50 mm / 135 kg + the box's **electric pump**): see the [assembly BOM](../../device-pro-acoustic/assembly/README.md).
For the full file ↔ topic index, see the [**source map**](../SOURCE-MAP.md).

---
→ [Build hub](README.md) · [iOS build](ios.md) · [Switch build](switch.md) · [How it works](../how-it-works.md) · [Source map](../SOURCE-MAP.md)

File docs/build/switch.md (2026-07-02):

# 🎛️ Build the **Switch** (digital piano / keyboard)

> 🌐 **English** · [日本語](../../i18n/ja/docs/build/switch.md) · [Deutsch](../../i18n/de/docs/build/switch.md)

The Switch is the small, inexpensive version for **digital** pianos and keyboards. Instead of a
motor, it switches the sustain **electronically** through the instrument's **sustain‑pedal jack** —
no motor, no airback. It uses the **same iOS app** and BLE board as the Pro.

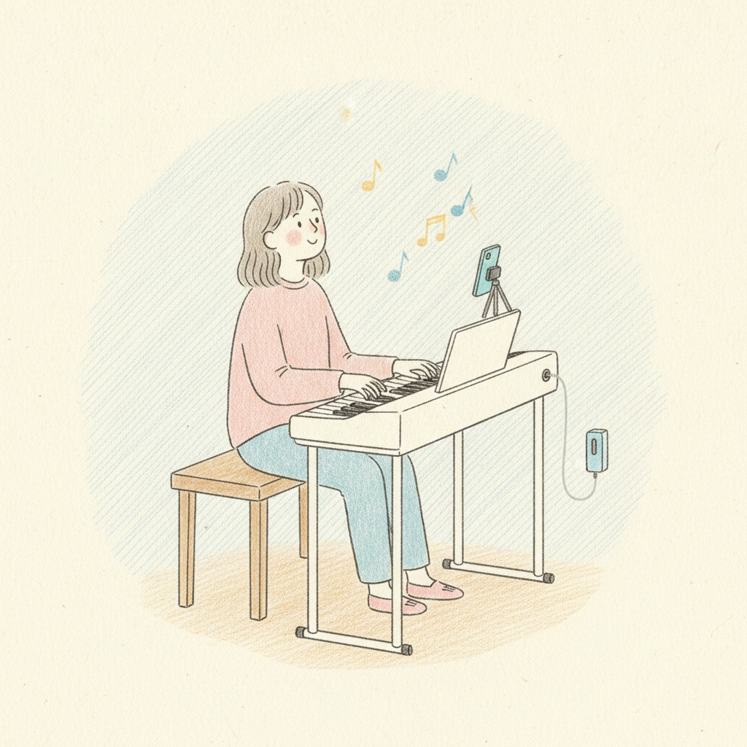
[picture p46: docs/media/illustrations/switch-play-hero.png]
A player at a digital keyboard plays foot‑free: a phone on a stand reads their head tilt while a tiny box on the keyboard's pedal jack switches the sustain

<sub>What you're building toward: foot‑free sustain on a digital piano, from a matchbox‑sized device. Illustration: AI‑generated (Saki Shiokawa style) © Shishido &amp; Associates.</sub>

> ✅ **Hardware confirmed.** The Switch electronics are now fully confirmed by the maker (H. Narusawa):
> board = **ItsyBitsy nRF52840**; a **ROHM `RU1J002YN`** logic‑level N‑MOSFET on **`GP13`** switches the
> sustain line **low‑side** (**no series resistor**); power = **2× AA**; it **starts on RESET**. The only
> draft part left is the **printed enclosure** (an AI draft in [`device-switch-electronic/assembly/`](../../device-switch-electronic/assembly/)).
> The **[Switch user‑manual video](https://youtu.be/XOVENtBsOp4)** shows it in use.

```
 1. Get the BLE board ─▶ 2. Add the sustain switch ─▶ 3. Wire to the pedal jack ─▶ 4. Flash ─▶ 5. Pair & use
```

## Before you start
- An **Adafruit ItsyBitsy nRF52840** BLE board (the Switch's board; has the onboard DotStar)
- A **ROHM `RU1J002YN`** N-channel logic-level **MOSFET** to switch the sustain line (**no series resistor**)
- **2× AA batteries** for power (no USB charging)
- A connector for the instrument's **sustain‑pedal jack** (commonly a 6.3 mm / TS jack)
- An iPhone/iPad with **Face ID** + the [iOS app](ios.md)

## Step 1 — Flash the BLE board
Flash the **standalone Switch firmware**
([`device-switch-electronic/firmware/`](../../device-switch-electronic/firmware/)) to the nRF52840
(double‑tap RESET → UF2 bootloader → upload). Full steps: [`docs/toolchain/`](../toolchain/).
Confirm it advertises (`bFaaaPSwitch_1…4`) in a BLE scanner.

## Step 2 — Add the sustain switch
Drive a **MOSFET** from the BLE board's `GP13` so it opens/closes the sustain contact (no series
resistor). Part = **ROHM `RU1J002YN`**; full reference circuit in
[`device-switch-electronic/hardware/`](../../device-switch-electronic/hardware/).

## Step 3 — Wire to the pedal jack
Wire the MOSFET across the instrument's **sustain‑pedal jack** (TS tip/sleeve). Match the **polarity /
normally‑open vs normally‑closed** behaviour of your instrument with the app's **on‑type / off‑type**
toggle (`n` / `f`).

## Step 4 — Pair & use
Build/install the [iOS app](ios.md), connect over Bluetooth, preset your **offset (threshold)** and
**multiplier** (together they set how fast the pedal follows your head), and play. See the
[Switch user manual](../user-manual/).

---
→ [Build hub](README.md) · [Pro build](pro.md) · [iOS build](ios.md)

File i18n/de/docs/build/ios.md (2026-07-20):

# 📱 Die iOS‑App bauen

> 🌐 [English](../../../../docs/build/ios.md) · [日本語](../../../ja/docs/build/ios.md) · **Deutsch**



Die App wird für **beide Geräte (Pro und Switch)** benötigt. Sie liest den Kopfwinkel per
Face‑ID‑Gesichts‑Tracking und sendet Pedalbefehle per Bluetooth. Du kannst sie auch einfach **kostenlos**
aus dem App Store **herunterladen** — das Bauen aus dem Quellcode ist für Entwickler, die anpassen oder
beitragen möchten.

> Referenz: [`ios-app/BUILD.md`](../../../../ios-app/BUILD.md) · [`ios-app/CODE-STRUCTURE.md`](../../../../ios-app/CODE-STRUCTURE.md) · [`ios-app/DESIGN-HIGHLIGHTS.md`](../../../../ios-app/DESIGN-HIGHLIGHTS.md)

```
 1. Voraussetzungen ─▶ 2. Projekt öffnen ─▶ 3. Signing setzen ─▶ 4. aufs Gerät bauen ─▶ 5. Berechtigungen ─▶ 6. Koppeln & einstellen
```

## Schritt 0 — Was du brauchst
- Einen **Mac** mit **Xcode 15+**
- Ein **iPhone/iPad mit TrueDepth‑(Face‑ID‑)Kamera** — nötig für das Kopf‑Tracking (der Simulator kann das nicht)
- Eine kostenlose **Apple‑ID** genügt zur Installation auf dem eigenen Gerät (ein bezahlter Apple‑Developer‑Account ist nur zum Verteilen nötig)

## Schritt 1 — Quellcode holen
Klone das Repository und öffne das Xcode‑Projekt:
```sh
git clone https://github.com/bfaaap/bfaaap_opensource.git
open bfaaap_opensource/ios-app/src/bFaaaPSwitch1.xcodeproj
```

## Schritt 2 — Dein Signing setzen
In Xcode: Projekt auswählen → **Signing & Capabilities** → **dein Team** wählen und die
**Bundle‑Identifier** auf etwas Eindeutiges ändern (die veröffentlichte ist zu `com.example.bfaaap`
bereinigt).

## Schritt 3 — Auf dem Gerät bauen & starten
Verbinde iPhone/iPad per USB, wähle es als Ziel und drücke **Run (▶)**. Erlaube beim ersten Start
**Kamera (Gesichts‑Tracking)** und **Bluetooth**.

## Schritt 4 — Koppeln & einstellen
Schalte das bFaaaP‑Gerät ein und verbinde dich aus der App. Stelle deine **Schwelle (Offset)** (wie
weit neigen) und deinen **Faktor** (Empfindlichkeit) ein; beide zusammen ergeben deine
**Reaktionsgeschwindigkeit** (wie schnell das Pedal dem Kopf folgt). Den BLE‑Ablauf siehe
[`ios-app/BLE-CONNECTION-FLOW.md`](../../../../ios-app/BLE-CONNECTION-FLOW.md), den Betrieb in
[`docs/operation/`](../../../../docs/operation/).

> Lieber nicht selbst bauen? Hol sie **kostenlos** aus dem **App Store**: <https://apps.apple.com/app/id1545866059>

---
→ [Build‑Hub](README.md) · [Pro bauen](pro.md) · [Switch bauen](switch.md)

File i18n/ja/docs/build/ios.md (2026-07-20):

# 📱 iOSアプリを作る

> 🌐 [English](../../../../docs/build/ios.md) · **日本語** · [Deutsch](../../../de/docs/build/ios.md)



アプリは**両方の装置（Pro・Switch）に必須**です。Face ID の顔トラッキングで頭の角度を読み取り、Bluetooth で
ペダルのコマンドを送ります。App Store から**無料でダウンロード**するだけでも使えます —— ソースからのビルドは、
カスタマイズや貢献をしたい開発者向けです。

> 参考：[`ios-app/BUILD.md`](../../../../ios-app/BUILD.md) · [`ios-app/CODE-STRUCTURE.md`](../../../../ios-app/CODE-STRUCTURE.md) · [`ios-app/DESIGN-HIGHLIGHTS.md`](../../../../ios-app/DESIGN-HIGHLIGHTS.md)

```
 1. 前提 ─▶ 2. プロジェクトを開く ─▶ 3. 署名を設定 ─▶ 4. 実機にビルド ─▶ 5. 権限許可 ─▶ 6. ペアリング・調整
```

## ステップ0 —— 必要なもの
- **Xcode 15+** が入った **Mac**
- **TrueDepth（Face ID）カメラ付きの iPhone/iPad** —— 頭部トラッキングに必須（シミュレータでは不可）
- 自分の端末へのインストールは無料の **Apple ID** で可（配布には有料の Apple Developer アカウントが必要）

## ステップ1 —— ソースを取得
リポジトリをクローンして Xcode プロジェクトを開きます：
```sh
git clone https://github.com/bfaaap/bfaaap_opensource.git
open bfaaap_opensource/ios-app/src/bFaaaPSwitch1.xcodeproj
```

## ステップ2 —— 署名を設定
Xcode で：プロジェクトを選択 → **Signing & Capabilities** → **自分の Team** を選び、**Bundle Identifier** を
一意のものに変更（公開版は `com.example.bfaaap` にサニタイズ済み）。

## ステップ3 —— 実機でビルド＆実行
iPhone/iPad を USB 接続し、実行先に選んで **Run（▶）**。初回起動時に **カメラ（顔トラッキング）** と
**Bluetooth** の許可を与えます。

## ステップ4 —— ペアリング・調整
bFaaaP 装置の電源を入れ、アプリから接続。**しきい値（オフセット）**（どれだけ傾けるか）と**倍率**（感度）を設定します。この2つで、頭に追従する速さ（**応答速度**）が決まります。
BLE の流れは [`ios-app/BLE-CONNECTION-FLOW.md`](../../../../ios-app/BLE-CONNECTION-FLOW.md)、操作は
[`docs/operation/`](../../../../docs/operation/) を参照。

> ビルドしない場合は **App Store** から**無料で**：<https://apps.apple.com/app/id1545866059>

---
→ [ビルドハブ](README.md) · [Pro を作る](pro.md) · [Switch を作る](switch.md)

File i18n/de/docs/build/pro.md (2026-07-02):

# 🎹 Den Pro bauen (akustisches Klavier)

> 🌐 [English](../../../../docs/build/pro.md) · [日本語](../../../ja/docs/build/pro.md) · **Deutsch**

Schritt‑für‑Schritt‑Anleitung für das Pro‑Gerät — ein kleiner Motor drückt das Haltepedal eines
akustischen Klaviers, fixiert durch ein *Airback*‑Luftkissen (nichts wird ans Klavier geschraubt).
Begriffe unklar? Siehe das [Glossar](../GLOSSARY.md). Hängengeblieben? Frag im
[KI‑gestützten Support](../ai-support.md).

Eine Pianistin spielt einen Flügel fußfrei: ein Smartphone am Notenständer liest die Kopfneigung, während ein kleines Gerät und ein Luftkissen das Haltepedal drücken
<sub>Das Ziel: fußfreies Pedalisieren an einem unveränderten Flügel. Illustration: KI‑generiert (Stil Saki Shiokawa) © Shishido &amp; Associates.</sub>

> 🚧 **Entwurf.** Der **Schaltplan** (Taguchi) und das **mechanische Layout** (H. Narusawas Bauskizze)
> sind nun bestätigt und unten eingearbeitet. Noch offen sind die **baubare Firmware des Schrittmotor‑Nachfolgers**
> (geplant ist ein **NEMA17** gleicher Größe, STEP/DIR; der ursprüngliche Motor ist EOL) und die **endgültige Variante der Druckteile**. Das
> **[Pro‑Einrichtungs‑Video](https://www.youtube.com/watch?v=_9YopbCYTmI)** zeigt es in echt.

```
 1. Teile drucken ─▶ 2. Elektronik holen ─▶ 3. Antrieb montieren ─▶ 4. Boards verdrahten
       ─▶ 5. Firmware flashen ─▶ 6. Montage + Airback ─▶ 7. Kraft einstellen & kalibrieren ─▶ 8. koppeln & spielen
```

Pro‑Bauschritte und die Repository‑Dateien, die jeder Schritt nutzt
<sub>Jeder Schritt verweist auf bestimmte Dateien — vollständiger Index in der [Quellenübersicht](../../../../docs/SOURCE-MAP.md).</sub>

Pro‑Antriebsmechanik

Der Antrieb ist eine **vertikale Säule**: ein Motor sitzt **neben** der Spindel und die **Druckstange
drückt senkrecht nach unten** aufs Haltepedal. Das Gesamtbild zeigt das
**[Referenzdesign](../../../../device-pro-acoustic/hardware/reference-design/)** — ein
[Systemarchitektur‑Diagramm](../../../../device-pro-acoustic/hardware/reference-design/pro-architecture.png)
und ein [mechanisches Layout‑Diagramm](../../../../device-pro-acoustic/hardware/reference-design/pro-mechanical-layout.png),
nach dem realen Gerät gezeichnet.

## Bevor du beginnst — was du brauchst
- Einen **3D‑Drucker** (Bett ≥240 mm hilft) + **PLA+**‑Filament
- Lötkolben, Schaltdraht, einfaches Handwerkzeug
- Die **Elektronik** (siehe [`PARTS-REFERENCE.md`](../../../../device-pro-acoustic/hardware/PARTS-REFERENCE.md)):
  Raspberry Pi **Pico**, **nRF52840**‑BLE‑Board, **IQ‑Fortiq**‑Motor *(oder den NEMA17‑Schrittmotor‑Nachfolger)*,
  ein **+5‑V‑Lüfter**, **HX711**, **2SK4017** MOSFET, Weganschlag‑Schieber, **24‑V‑Netzteil**
- Rahmenmaterial: **2040‑ + 2080‑ + 4040‑Aluprofil**, ein **GT-2‑262‑Riemen** + **T60/T60‑Riemenscheiben**,
  eine **T10‑Gewindespindel** (**Steigung 16 mm/U, 150 mm**), Druckstange
- Das **Airback**‑Set: ein **WINBAG**‑Luftheber + eine kleine **elektrische Luftpumpe** (in der Box,
  angesteuert über **GP12** per **2SK4017**‑MOSFET und einen Panel‑**PUMP SW**) — das gebaute Gerät nutzt den Handball **nicht**
- Ein iPhone/iPad mit Face ID + die [iOS‑App](ios.md)

## Schritt 1 — Mechanische Teile drucken
1. Öffne die `.stl` / `.3mf` in [`hardware/3d-print/`](../../../../device-pro-acoustic/hardware/3d-print/) in einem Slicer (Bambu Studio, PrusaSlicer, OrcaSlicer …).
2. Nutze **PLA+**, **0,1–0,2 mm** Toleranz; achte auf die Ausrichtung (Löcher ohne Stützen). Siehe die [3D‑Druck‑Hinweise](../../../../device-pro-acoustic/hardware/3d-print/README.md).
3. Drucke Rahmenteile, PCB‑Halter, Strombox, Druckstange und Abdeckungen.

## Schritt 2 — Elektronik beschaffen
Bestelle die Teile aus [`PARTS-REFERENCE.md`](../../../../device-pro-acoustic/hardware/PARTS-REFERENCE.md).
**Hinweis:** der originale IQ/Fortiq‑Motor ist **EOL** — der geplante Nachfolger ist ein **NEMA17‑("17‑Typ‑")Schrittmotor gleicher Größe** (nutzt den vorhandenen Rahmen), **STEP/DIR**. Siehe [`HARDWARE-AVAILABILITY.md`](../../../../device-pro-acoustic/HARDWARE-AVAILABILITY.md).

## Schritt 3 — Antriebseinheit montieren
Der Antrieb ist eine **vertikale Säule** (siehe das [Referenzdesign](../../../../device-pro-acoustic/hardware/reference-design/)):
1. Baue den Rahmen — eine **vertikale 2040‑Säule** (L ≈ 200 mm) auf einer **2080‑Basis** (L ≈ 200 mm).
2. Montiere den **Motor neben der Spindel** (oben) und koppele ihn mit dem **GT-2‑262‑Riemen** über
   **zwei T60‑Riemenscheiben (1:1)** — der Riemen *versetzt* den Motor nur neben die Spindel, er ist **keine** Untersetzung.
3. Setze die **vertikale T10‑Gewindespindel** (Steigung **16 mm/U**) an der **linken Seite der 2040‑Säule** ein; ihre
   **Mutter/Schlitten** fährt am Rahmen hinab und trägt eine **Druckstange** — ein **2040‑Profil L=75 mm** mit einem
   **15‑mm‑PLA‑Teil** oben (hält die Spindel­mutter) und einem **PLA‑Teil mit Hartgummi‑Spitze** unten (gesamt **115 mm**) —,
   die **senkrecht nach unten** aufs Haltepedal drückt. Bringe den **+5‑V‑Lüfter** am Motor an.
4. Bringe die Boards in der gedruckten **Elektronikbox** (BLE + Pico + Airjack‑Pumpe) unter und das Netzteil in der **Strombox (PW)**.

Antriebseinheit + Airback‑Komponenten

## Schritt 4 — Boards verdrahten
Folge dem Schaltplan in [`hardware/schematic/`](../../../../device-pro-acoustic/hardware/schematic/). Wichtige Verbindungen (Referenz v039B):
- Motor‑Seriell → Pico **GP4 / GP5**
- **HX711** Luftdruck → **GP2 / GP3**; Luftpumpe über **MOSFET → GP12** auf +5 V
- Weganschlag‑Schieber → **ADC0 / GP26**; **DIP‑Schalter** für Kraft/Hub
- BLE‑Board ↔ Pico über **UART (`Serial1`)**, gemeinsame Masse; **24 V** zum Motor

I/O‑Panel
Stromstecker

> 🚧 *Die genaue Pin-/Stecker‑Tabelle wird mit den Bauenden bestätigt — gesicherte Details in
> [`DISCORD-FINDINGS.md`](../../../../device-pro-acoustic/DISCORD-FINDINGS.md).*

## Schritt 5 — Firmware flashen
Flashe **zwei Boards** (alle Schritte in [`docs/toolchain/`](../../../../docs/toolchain/)):
- **BLE‑Board (nRF52):** Adafruit‑nRF52‑Support installieren, RESET zweimal tippen, BLE‑Sketch hochladen.
- **Hauptplatine (Pico):** den **arduino‑pico‑(Philhower‑)Core** + HX711 + IQ‑Bibliothek installieren,
  **BOOTSEL** halten und **`bFaaaP_autopro_pico_v039B_…ino`** hochladen *(nicht den Schrittmotor‑Snapshot `v052B` verwenden)*.

## Schritt 6 — Am Klavier montieren + Airback
1. Platziere den Antrieb so, dass die Druckstange über dem Haltepedal sitzt.
2. Fixiere mit dem **Airback**: führe den **Luftschlauch** von der **elektrischen Pumpe** der Box zum WINBAG
   und pumpe ihn mit dem Panel‑**PUMP SW** gegen ein Nachbarpedal auf, um
   die Reaktionskraft aufzunehmen — nichts berührt die Klavieroberfläche. Siehe [`hardware/airback/`](../../../../device-pro-acoustic/hardware/airback/).

Airback‑Luftventil

## Schritt 7 — Druckkraft einstellen & kalibrieren
- Stelle am **DIP‑Schalter** die Druckkraft **20–35 W** (1‑W‑Schritte) und den Hubweg **5–20 mm** ein.
  Beginne im unteren 20‑W‑Bereich und erhöhe, bis der Ton zuverlässig klingt (Kraft ist **leistungsbasiert**,
  klavierabhängig).
- Führe die Selbstkalibrierung aus; beobachte den **Serial Monitor @ 115200**. Eine Sicherheitsgrenze stoppt Wege über ~50 mm.

## Schritt 8 — App koppeln & spielen
Baue/installiere die [iOS‑App](ios.md), koppele per Bluetooth, stelle deinen **Offset (Schwelle)** &
**Multiplikator** ein (zusammen legen sie fest, wie schnell das Pedal dem Kopf folgt — siehe
[Funktionsweise](../how-it-works.md)), kalibriere den Kopfwinkel‑Nullpunkt — und spiele. Siehe
[`docs/operation/`](../../../../docs/operation/).

## Mechanische Stückliste & CAD‑Referenz

Die vollständige Stückliste (mit Preisen, Zukaufteilen) steht in
[`assembly/README.md`](../../../../device-pro-acoustic/assembly/README.md). Unten die **3D‑gedruckten
Teile** mit aus dem **CAD (BREP) gemessenen Maßen** und der **bearbeitbaren Quelldatei** je Teil.

> 🚧 Die **endgültige Variante** jedes Teils und die **Schraubenliste** werden mit dem Hardware‑Autor
> (H. Narusawa) bestätigt; die folgenden Dateien sind die neuesten aus dem Discord‑CAD‑Satz.

| Gedrucktes Teil | Maße (mm, L×B×H) | Bearbeitbares CAD — `device-pro-acoustic/hardware/cad/from-discord-2025/` |
|---|---|---|
| Neues Gehäuse **AA** | 135×120×62 | `bFaaaP_AA.FCStd` (STL: `3d-print/from-discord-2025/bFaaaP_AA-A.stl`) |
| Neues Gehäuse **CC / DD** | 250×100×60 / 250×100×10 | STL `bFaaaP_CC-CC.stl` / `bFaaaP_DD-DD.stl` *(großer Drucker nötig)* |
| Basis + Airjack | 292×124×50 | `bfaaap_base_plus_airjack2.FCStd` |
| Basis + Halter (osae) | 260×121×55 | `bfaaap_base_plus_osae_d.FCStd` |
| Luftbox | 200×125×35 | `bfaaap_airbox_a_2.FCStd` *(Varianten a/a‑1/a‑2/c)* |
| Schieber (Weganschlag) | 243×132×25 | `bfaaap_slide2_20241028.FCStd` |
| DIP‑Schalter‑Box | 60×30×6 | `bfaaap_dipsw_box_top_bot.FCStd` |
| Handsteuerungs‑Knöpfe | 50×50×10 / 50×50×20 | `bfaaap_nob_a.FCStd` / `bfaaap_nob_b.FCStd` |
| Druckstange | (siehe CAD) | `bfaaap_push_poll.FCStd` |
| **Antriebsbaugruppe (Referenz‑Layout)** | 530×290×216 | `bfaaap_belt_gotai14.FCStd` |

Zukauf‑Mechanikteile (IQ‑Motor → **NEMA17**‑Nachfolger, **T10‑Gewindespindel** Steigung **16 mm/U** / 150 mm, **GT-2‑262‑Riemen**, **T60‑Riemenscheiben**
5/10 mm Bohrung, Lager, **2040‑ + 2080‑ + 4040‑Aluprofil**, **WINBAG‑Luftheber** 160×150 mm / ≤50 mm / 135 kg
+ elektrische Pumpe der Box): siehe die [Stückliste](../../../../device-pro-acoustic/assembly/README.md). Vollständiger Datei‑↔‑Thema‑Index:
[**Quellenübersicht**](../../../../docs/SOURCE-MAP.md).

---
→ [Build‑Hub](README.md) · [iOS bauen](ios.md) · [Switch bauen](switch.md) · [Funktionsweise](../how-it-works.md) · [Quellenübersicht](../../../../docs/SOURCE-MAP.md)

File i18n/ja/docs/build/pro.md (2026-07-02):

# 🎹 Pro を作る（アコースティックピアノ）

> 🌐 [English](../../../../docs/build/pro.md) · **日本語** · [Deutsch](../../../de/docs/build/pro.md)

Pro 装置を作る手順です —— アコースティックピアノのサステインペダルを小さなモーターで押し、*エアバック*の
空気クッションで固定します（ピアノにネジ留め不要）。用語が不安なら[用語集](../GLOSSARY.md)を。
詰まったら[AI支援サポート](../ai-support.md)で質問を。

グランドピアノを足を使わず演奏：譜面台のスマホが頭の傾きを読み、小さな装置と空気クッションがサステインを押す
<sub>めざす姿：未改造のグランドでフットフリーのペダリング。イラスト：AIイラスト：Harmonia による塩川紗季風 © 宍戸＆アソシエーツ。</sub>

> 🚧 **ドラフト**：**電気回路**（田口）と**機械レイアウト**（成澤の手書き）は確定済みで下記に反映しています。
> 確定待ちは **ステッパ後継のビルド可能なファーム**（後継機は同寸の **NEMA17**・STEP/DIR の予定。オリジナルは EOL）と **最終的な印刷部品の変種** です。
> **[Pro 設置ウォークスルー動画](https://www.youtube.com/watch?v=_9YopbCYTmI)** で実際の様子が見られます。

```
 1. 部品を印刷 ─▶ 2. 電子部品を入手 ─▶ 3. ドライブを組立 ─▶ 4. ボードを配線
       ─▶ 5. ファーム書込 ─▶ 6. 取付＋エアバック ─▶ 7. 力の設定＆校正 ─▶ 8. ペアリングして演奏
```

Pro のビルド工程と各工程が使うリポジトリ内ファイル
<sub>各工程は特定のファイルに対応します —— 完全な索引は[ソースマップ](../../../../docs/SOURCE-MAP.md)。</sub>

Pro の駆動機構

駆動は**縦型コラム**です：モーターはスクリューの**横**に置かれ、**押し棒が真下に**サステインペダルを押します。
全体像は **[リファレンス設計](../../../../device-pro-acoustic/hardware/reference-design/)** を参照
—— 実機に基づく[システムアーキテクチャ図](../../../../device-pro-acoustic/hardware/reference-design/pro-architecture.png)
と[機械レイアウト図](../../../../device-pro-acoustic/hardware/reference-design/pro-mechanical-layout.png)があります。

## はじめる前に —— 必要なもの
- **3Dプリンタ**（ベッド≥240mm があると安心）＋ **PLA+** フィラメント
- はんだごて、配線材、基本工具
- **電子部品**（[`PARTS-REFERENCE.md`](../../../../device-pro-acoustic/hardware/PARTS-REFERENCE.md) 参照）：
  Raspberry Pi **Pico**、**nRF52840** BLEボード、**IQ‑Fortiq** モーター *（または NEMA17 後継ステッパ）*、
  **+5V 冷却ファン**、**HX711**、**2SK4017** MOSFET、可動上限スライダ、**24V電源**
- フレーム材：**2040＋2080＋4040 アルミ押出**、**GT-2‑262 ベルト**＋**T60/T60 プーリ**、**T10リードスクリュー**（**リード16mm/回・150mm**）、押し棒
- **エアバック**キット：**WINBAG** エアジャック＋小型の**電動エアポンプ**（BOX内に収納、**GP12**→**2SK4017** MOSFET
  で駆動、パネルの **PUMP SW** で操作）—— 実機は WINBAG の手動球は**使いません**
- Face ID 付き iPhone/iPad ＋ [iOSアプリ](ios.md)

## ステップ1 —— 機構部品を印刷
1. [`hardware/3d-print/`](../../../../device-pro-acoustic/hardware/3d-print/) の `.stl` / `.3mf` をスライサー（Bambu Studio、PrusaSlicer、OrcaSlicer 等）で開く。
2. **PLA+**、公差 **0.1〜0.2mm**、向きに注意（穴はサポートなし）。[3Dプリントの注意](../../../../device-pro-acoustic/hardware/3d-print/README.md)参照。
3. フレーム部品、PCBマウント、電源ボックス、押し棒、カバーを印刷。

## ステップ2 —— 電子部品を入手
[`PARTS-REFERENCE.md`](../../../../device-pro-acoustic/hardware/PARTS-REFERENCE.md) から発注。
**注意**：オリジナルの IQ/Fortiq モーターは **EOL** —— 後継は**同寸の NEMA17（17型）ステッパ**（既存フレームを流用）で
**STEP/DIR 方式**の予定。[`HARDWARE-AVAILABILITY.md`](../../../../device-pro-acoustic/HARDWARE-AVAILABILITY.md)参照。

## ステップ3 —— ドライブユニットを組立
駆動は**縦型コラム**です（[リファレンス設計](../../../../device-pro-acoustic/hardware/reference-design/)参照）：
1. フレームを組む —— **縦の 2040 支柱**（L≈200mm）を **2080 の土台**（L≈200mm）に立てる。
2. **モーターをスクリューの横**（上部）に取り付け、**GT-2‑262 ベルト**で **T60 プーリ2個（1:1）**を介して連結
   —— ベルトはモーターを横に*オフセット*するためで、**減速ではありません**。
3. **縦の T10 リードスクリュー**（リード**16mm/回**）を **2040 支柱の左側**に取り付ける。**ナット/キャリッジ**が
   フレームを下降し、**押し棒**——**2040 L=75mm** に上部 **15mm の PLA**（ナット保持）と下部の **PLA＋硬質ゴム先端**
   （計 **115mm**）——が サステインペダルを**真下に**押す。モーターに **+5V 冷却ファン**を付ける。
4. ボードは印刷した**電子部品BOX**（BLE＋Pico＋エアジャックポンプ）に、電源は**電源BOX（PW）**に収める。

ドライブユニット＋エアバック部品

## ステップ4 —— ボードを配線
[`hardware/schematic/`](../../../../device-pro-acoustic/hardware/schematic/) の回路図に従う。主な接続（参照 v039B）：
- モーターシリアル → Pico **GP4 / GP5**
- **HX711** 空気圧 → **GP2 / GP3**；エアポンプは **MOSFET → GP12** 経由で +5V
- 可動上限スライダ → **ADC0 / GP26**；力/昇降は **DIPスイッチ**
- BLEボード ↔ Pico は **UART（`Serial1`）**、GND共通；モーターに **24V**

I/Oパネル
電源コネクタ

> 🚧 *正確なピン/コネクタ表は作り手と確認中 —— 確定済みの詳細は
> [`DISCORD-FINDINGS.md`](../../../../device-pro-acoustic/DISCORD-FINDINGS.md) を参照。*

## ステップ5 —— ファームウェアを書き込み
**2枚のボード**に書き込み（手順は [`docs/toolchain/`](../../../../docs/toolchain/)）：
- **BLEボード（nRF52）**：Adafruit nRF52 サポートを入れ、RESET 2回押し、BLEスケッチをアップロード。
- **メイン（Pico）**：**arduino‑pico（Philhower）コア**＋HX711＋IQライブラリを入れ、**BOOTSEL** を押しながら
  **`bFaaaP_autopro_pico_v039B_…ino`** をアップロード *（ステッパ版 `v052B` は使わない）*。

## ステップ6 —— ピアノに取付＋エアバック
1. 押し棒がサステインペダルの上に来るようにドライブを配置。
2. **エアバック**で固定：BOX内の**電動ポンプ**から **エアチューブ** を WINBAG に通し、パネルの **PUMP SW** で
   隣のペダルに膨らませて反力を吸収 —— ピアノの塗装に触れません。
   [`hardware/airback/`](../../../../device-pro-acoustic/hardware/airback/)参照。

エアバックのエア弁

## ステップ7 —— 押下力の設定＆校正
- **DIPスイッチ**で押下力 **20〜35W**（1W刻み）と昇降距離 **5〜20mm** を設定。20W台前半から始め、確実に鳴るまで
  上げる（力は**電力ベース**でピアノ依存）。
- 自己校正を実行し、**シリアルモニタ@115200** を確認。約50mm超で安全停止します。

## ステップ8 —— アプリでペアリングして演奏
[iOSアプリ](ios.md)をビルド/インストールし、Bluetooth でペアリング、**オフセット（しきい値）**と**倍率**を
プリセット（この2つでペダルが頭に追従する速さが決まります —— [仕組み](../how-it-works.md)参照）、頭の角度の
ゼロを校正して演奏。[`docs/operation/`](../../../../docs/operation/)参照。

## 機械BOM＆CADリファレンス

価格・市販部品込みの完全な BOM は
[`assembly/README.md`](../../../../device-pro-acoustic/assembly/README.md) にあります。以下は **3Dプリント部品**で、
**CAD（BREP）から実測した寸法**と各部品の**編集用ソースファイル**を示します（印刷・改変に利用可）。

> 🚧 各部品の**最終変種**と**ファスナー一覧**は作り手（成澤）と確認中。下記は Discord CAD セットの最新版です。

| 印刷部品 | 寸法 (mm, L×W×H) | 編集用CAD —— `device-pro-acoustic/hardware/cad/from-discord-2025/` |
|---|---|---|
| 新筐体 **AA** | 135×120×62 | `bFaaaP_AA.FCStd`（STL: `3d-print/from-discord-2025/bFaaaP_AA-A.stl`） |
| 新筐体 **CC / DD** | 250×100×60 / 250×100×10 | STL `bFaaaP_CC-CC.stl` / `bFaaaP_DD-DD.stl` *（大型プリンタ要）* |
| ベース＋エアジャック | 292×124×50 | `bfaaap_base_plus_airjack2.FCStd` |
| ベース＋押さえ(osae) | 260×121×55 | `bfaaap_base_plus_osae_d.FCStd` |
| エアボックス | 200×125×35 | `bfaaap_airbox_a_2.FCStd` *（変種 a/a‑1/a‑2/c あり）* |
| スライダ（可動上限） | 243×132×25 | `bfaaap_slide2_20241028.FCStd` |
| DIPスイッチ箱 | 60×30×6 | `bfaaap_dipsw_box_top_bot.FCStd` |
| ハンドコントローラのノブ | 50×50×10 / 50×50×20 | `bfaaap_nob_a.FCStd` / `bfaaap_nob_b.FCStd` |
| 押し棒 | （CAD参照） | `bfaaap_push_poll.FCStd` |
| **ドライブ全体（参照レイアウト）** | 530×290×216 | `bfaaap_belt_gotai14.FCStd` |

市販の機械部品（IQモーター→**NEMA17** 後継、**T10リードスクリュー** リード**16mm/回**／150mm、**GT-2‑262 ベルト**、**T60プーリ** 5/10mmボア、
ベアリング、**2040＋2080＋4040** アルミ押出、**WINBAG エアジャック** 160×150mm／≤50mm／135kg ＋BOX内の**電動ポンプ**）は
[assembly BOM](../../../../device-pro-acoustic/assembly/README.md)参照。ファイル↔トピックの完全索引は
[**ソースマップ**](../../../../docs/SOURCE-MAP.md)へ。

---
→ [ビルドハブ](README.md) · [iOS を作る](ios.md) · [Switch を作る](switch.md) · [仕組み](../how-it-works.md) · [ソースマップ](../../../../docs/SOURCE-MAP.md)

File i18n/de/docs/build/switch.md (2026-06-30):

# 🎛️ Den Switch bauen (Digitalklavier / Keyboard)

> 🌐 [English](../../../../docs/build/switch.md) · [日本語](../../../ja/docs/build/switch.md) · **Deutsch**

Der Switch ist die kleine, günstige Version für **digitale** Klaviere und Keyboards. Statt eines
Motors schaltet er das Sustain **elektronisch** über die **Pedalbuchse** des Instruments — kein
Motor, kein Airback. Er nutzt **dieselbe iOS‑App und dasselbe BLE‑Board** wie der Pro.

> 🚧 **Entwurf:** der Großteil der Switch‑Hardware ist nun bestätigt (Board = ItsyBitsy nRF52840; ein
> **MOSFET** an `GP13` schaltet die Sustain‑Leitung, **kein Serienwiderstand**). Offen bleibt nur das
> genaue MOSFET‑Bauteil und seine Verdrahtung — siehe
> [`device-switch-electronic/firmware/`](../../../../device-switch-electronic/firmware/). Das
> **[Switch‑Handbuch‑Video](https://youtu.be/XOVENtBsOp4)** zeigt die Anwendung.

```
 1. BLE‑Board holen ─▶ 2. Sustain‑Schalter ergänzen ─▶ 3. an Pedalbuchse verdrahten ─▶ 4. flashen ─▶ 5. koppeln & nutzen
```

## Bevor du beginnst
- Ein **Adafruit ItsyBitsy nRF52840**‑BLE‑Board (das Board des Switch; mit der onboard‑DotStar)
- Ein **ROHM `RU1J002YN`** N‑Kanal‑Logiklevel‑**MOSFET** zum Schalten der Sustain‑Leitung (**kein Serienwiderstand**)
- **2× AA‑Batterien** zur Stromversorgung (kein USB‑Laden)
- Ein Stecker für die **Sustain‑Pedalbuchse** des Instruments (meist 6,3‑mm‑/TS‑Klinke)
- Ein iPhone/iPad mit Face ID + die [iOS‑App](ios.md)

## Schritt 1 — BLE‑Board flashen
Flashe die **eigenständige Switch‑Firmware**
([`device-switch-electronic/firmware/`](../../../../device-switch-electronic/firmware/)) auf das
nRF52840 (RESET zweimal tippen → UF2‑Bootloader → hochladen). Alle Schritte:
[`docs/toolchain/`](../../../../docs/toolchain/). Prüfe, dass es (`bFaaaPSwitch_1…4`) in einem
BLE‑Scanner erscheint.

## Schritt 2 — Sustain‑Schalter ergänzen
Steuere über `GP13` des BLE‑Boards einen **MOSFET** an, der den Sustain‑Kontakt öffnet/schließt (kein
Serienwiderstand). Bauteil = **ROHM `RU1J002YN`**; vollständige Referenzschaltung in
[`device-switch-electronic/hardware/`](../../../../device-switch-electronic/hardware/).

## Schritt 3 — An die Pedalbuchse verdrahten
Verdrahte den MOSFET über die **Sustain‑Pedalbuchse** des Instruments (TS Spitze/Schaft). Passe die
**Polarität / Öffner‑ vs. Schließer‑Verhalten** mit dem **On‑Typ / Off‑Typ**‑Schalter der App
(`n` / `f`) an.

## Schritt 4 — Koppeln & nutzen
Baue/installiere die [iOS‑App](ios.md), verbinde dich per Bluetooth, stelle deinen **Offset (Schwelle)** und **Multiplikator** ein und spiele (die beiden legen die Reaktionsgeschwindigkeit fest). Siehe das [Switch‑Handbuch](../../../../docs/user-manual/).

---
→ [Build‑Hub](README.md) · [Pro bauen](pro.md) · [iOS bauen](ios.md)

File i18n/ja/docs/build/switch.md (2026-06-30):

# 🎛️ Switch を作る（デジタルピアノ／キーボード）

> 🌐 [English](../../../../docs/build/switch.md) · **日本語** · [Deutsch](../../../de/docs/build/switch.md)

Switch は**デジタル**ピアノ/キーボード向けの小型・低コスト版です。モーターの代わりに、楽器の
**サステインペダル端子**を通じてサステインを**電子的に**切り替えます —— モーターもエアバックも不要。
Pro と**同じ iOS アプリと BLE ボード**を使います。

> 🚧 **ドラフト**：Switch のハードウェアの大部分が確定しました（ボード＝ItsyBitsy nRF52840、`GP13` の
> **MOSFET** がサステイン線を開閉、**直列抵抗なし**）。残る詳細は MOSFET の正確な部品と配線です —— 
> [`device-switch-electronic/firmware/`](../../../../device-switch-electronic/firmware/) を参照。
> **[Switch 取扱説明動画](https://youtu.be/XOVENtBsOp4)** で使用例が見られます。

```
 1. BLEボード入手 ─▶ 2. サステインスイッチを追加 ─▶ 3. ペダル端子へ配線 ─▶ 4. 書き込み ─▶ 5. ペアリング・使用
```

## はじめる前に
- **Adafruit ItsyBitsy nRF52840** BLEボード（Switch 用ボード。オンボード DotStar 搭載）
- サステイン線を切り替える **ROHM `RU1J002YN`** N チャネル ロジックレベル **MOSFET**（**直列抵抗なし**）
- 電源用の **単3電池 2本**（USB充電なし）
- 楽器の**サステインペダル端子**用コネクタ（一般に 6.3mm / TS ジャック）
- Face ID 付き iPhone/iPad ＋ [iOSアプリ](ios.md)

## ステップ1 —— BLEボードに書き込み
**スタンドアロン Switch ファームウェア**
（[`device-switch-electronic/firmware/`](../../../../device-switch-electronic/firmware/)）を nRF52840
に書き込みます（RESET 2回押し → UF2 ブートローダ → アップロード）。手順は
[`docs/toolchain/`](../../../../docs/toolchain/)。BLE スキャナで広告（`bFaaaPSwitch_1…4`）が見えることを確認。

## ステップ2 —— サステインスイッチを追加
BLEボードの `GP13` で **MOSFET** を駆動し、サステイン接点を開閉します（直列抵抗なし）。
部品＝**ROHM `RU1J002YN`**。完全な参照回路は
[`device-switch-electronic/hardware/`](../../../../device-switch-electronic/hardware/) を参照。

## ステップ3 —— ペダル端子へ配線
楽器の**サステインペダル端子**（TS チップ/スリーブ）に MOSFET を配線します。楽器ごとの**極性／ノーマル
オープン・ノーマルクローズ**は、アプリの **on-type / off-type**（`n` / `f`）で合わせます。

## ステップ4 —— ペアリング・使用
[iOSアプリ](ios.md)をビルド/インストールし、Bluetooth で接続、**オフセット（しきい値）**と**倍率**をプリセットして演奏します（この2つで応答速度が決まります）。
[Switch 取扱説明](../../../../docs/user-manual/)を参照。

---
→ [ビルドハブ](README.md) · [Pro を作る](pro.md) · [iOS を作る](ios.md)

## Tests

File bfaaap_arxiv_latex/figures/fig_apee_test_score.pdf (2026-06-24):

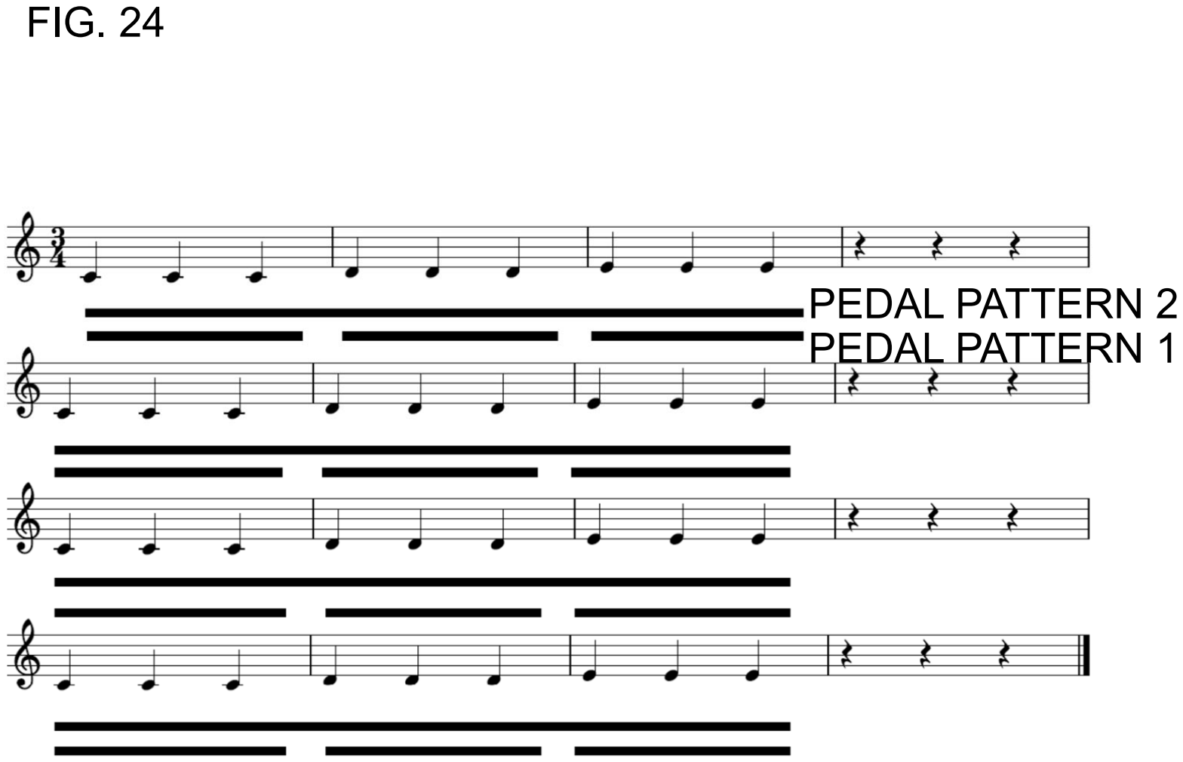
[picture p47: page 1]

FIG. 24

PEDAL PATTERN 2
PEDAL PATTERN 1

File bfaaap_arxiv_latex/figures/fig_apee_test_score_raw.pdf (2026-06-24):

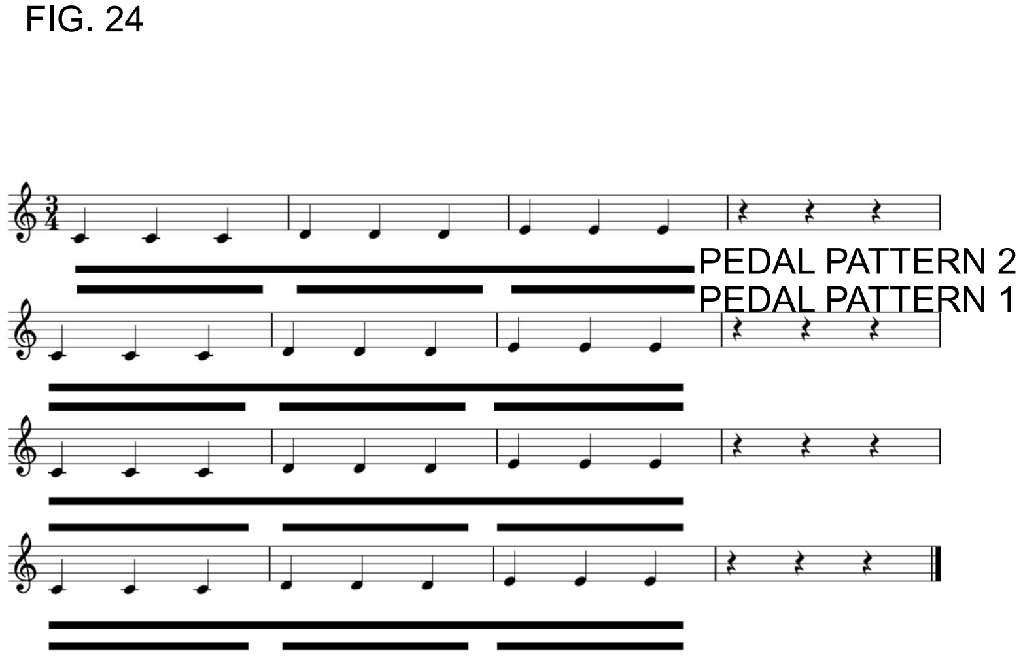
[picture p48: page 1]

FIG. 24

PEDAL PATTERN 2
PEDAL PATTERN 1

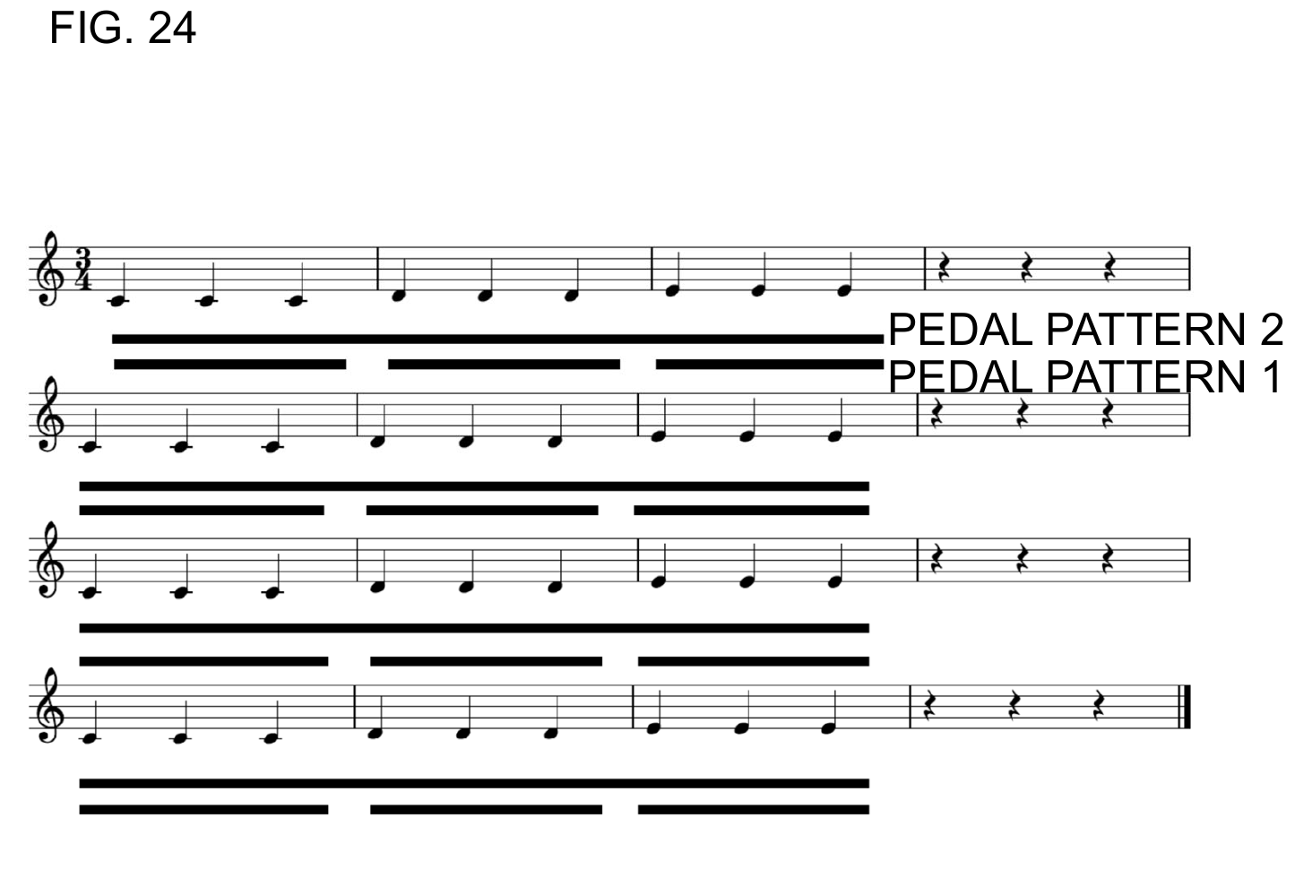
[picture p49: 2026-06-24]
docs/media/diagrams/fig-apee-test-score.png

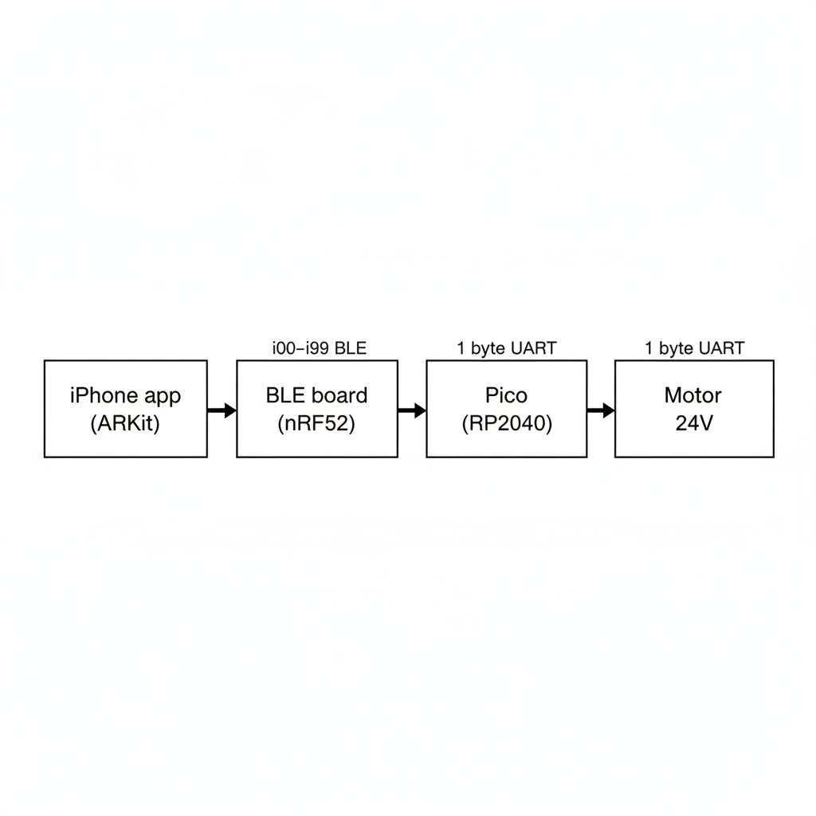
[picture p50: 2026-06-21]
docs/media/qa/3/signal-flow.png

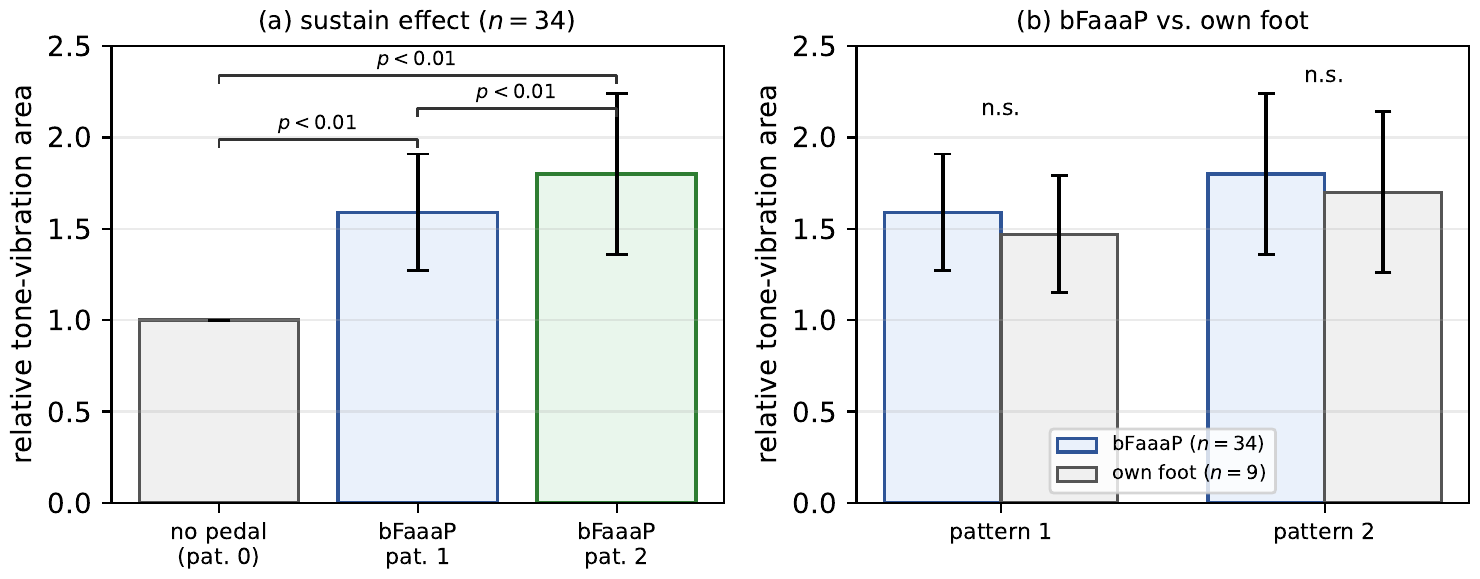
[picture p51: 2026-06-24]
docs/media/diagrams/fig-apee-results.png

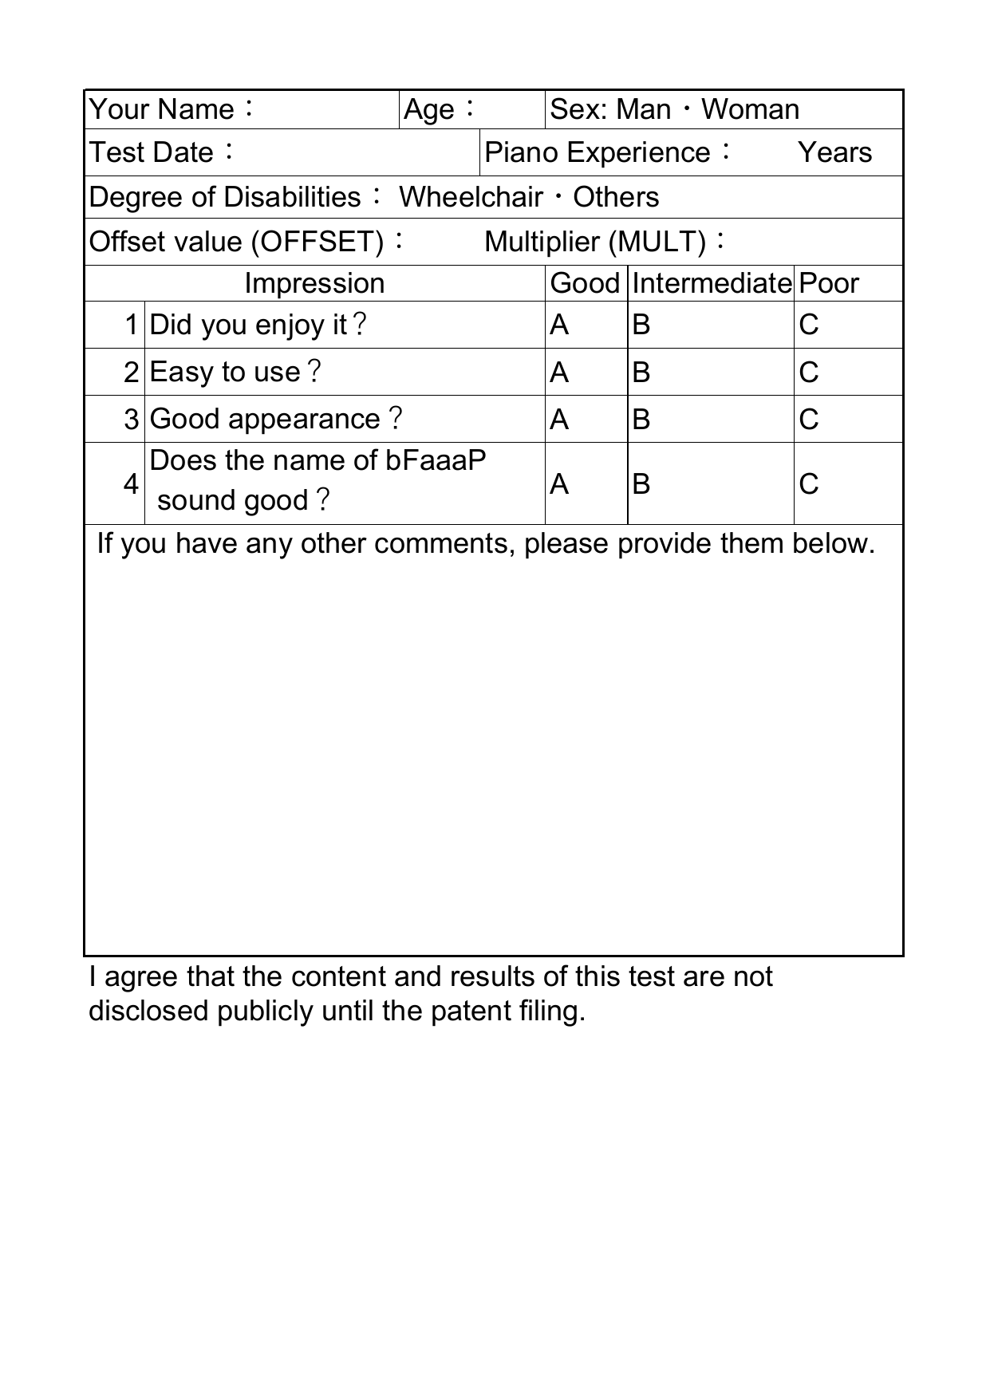
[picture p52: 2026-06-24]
docs/history/pct-original-figures/previews/apee-06-test-protocol.png

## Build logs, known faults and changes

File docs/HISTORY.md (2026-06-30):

# bFaaaP — project history

> 🌐 **English** · [日本語](../i18n/ja/docs/HISTORY.md) · [Deutsch](../i18n/de/docs/HISTORY.md)

Platanus with bFaaaP poster

*bFaaaP = **b**arrier-**F**ree **a**ssist **a**s **a** **P**edal — an AI assistive
piano‑pedal system. Project site: <https://bfaaap.com>*

## Origin (2018)

bFaaaP started in **January 2018**. A **wheelchair user** — a client of architect
**Masahiro Ootaki** — asked: *"I'd like to motorize the piano's pedal so I can
press it."* Seated at the piano in a wheelchair they could play the keys, but
could not reach the pedals, so the playing lacked expression. That request became
bFaaaP.

The very first prototype, **"bFaaap‑1"** (piano‑pedal trial #1, **2018‑02‑10**),
was a white box weighted with concrete, full of electronics and wiring — "first,
build *something* that moves." Its original drawings — the **glasses‑mounted sensor**
(a design‑registered idea) and the sound‑proof chamber, with the control law already
in place — are collected, with hand sketches, in
[**bFaaaP 1 — where the invention began**](history/bfaaap-1-original/README.md).

## Early design (bFaaaP1–4)

The early system had two parts, controlled by a microcontroller (Arduino IDE,
M5Stack / ESP32 era; wooden enclosure for bFaaaP4):

- a **head‑mounted motion sensor** — a 9‑axis IMU on an **eyeglass frame**,
  reading the head's fore/aft motion, and
- an **actuator** placed in front of the pedal.

A **PCT international patent** was filed in 2018; the method was later granted in
Japan as **特許第6726319号 / 第7004771号** (the head‑angle **offset + multiplier** scheme,
which together set the **response speed**).

Public debut: ~2019, at a piano recital of Kyoko Yamaguchi's class "Fleur"
(MUSICASA, Yoyogi‑Uehara).

## Evolution to today

The head‑mounted IMU was replaced by **smartphone AR face tracking** (iOS AI),
sending the head angle over **BLE** to the pedal device (now a Raspberry Pi Pico
+ Adafruit ItsyBitsy nRF52840). Two product lines emerged:

- **Switch** — for electric pianos & keyboards (electronic sustain‑jack switch),
- **Pro** — for acoustic pianos (a motor presses the sustain pedal).

Recent demonstrations:

- **2024** — Kodai festival, Institute of Science Tokyo
  (<https://www.youtube.com/watch?v=Im4jsed1tJQ>)
- **2025** — Platanus Suzukake Concert with bFaaaP
  (<https://www.youtube.com/watch?v=V3cXeNW9jXY>)

## People

Developed by the bFaaaP / **Platanus** members:

- **Tomoyuki Shishido** — iOS app
- **Hiroyuki Narusawa** — pedal device / firmware
- **Masahiro Ootaki** — architect; design & overall coordination
- **Kyoko Yamaguchi**, **Daisuke Tokushige**, and others

> The goal: an **inclusive** design so anyone — people with limb disabilities,
> small children, the elderly — can enjoy playing the piano with a pedal.

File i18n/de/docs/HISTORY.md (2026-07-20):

# bFaaaP — Projektgeschichte

> 🌐 [English](../../../docs/HISTORY.md) · [日本語](../../ja/docs/HISTORY.md) · **Deutsch**

Platanus‑with‑bFaaaP‑Plakat

*bFaaaP = **b**arrier‑**F**ree **a**ssist **a**s **a** **P**edal — ein KI‑gestütztes System zur
Bedienung des Klavierpedals. Projektseite: <https://bfaaap.com>*

## Ursprung (2018)

bFaaaP begann im **Januar 2018**. Eine **Rollstuhlnutzerin** — Klientin des Architekten
**Masahiro Ootaki** — fragte: *„Ich würde gern das Klavierpedal motorisieren, damit ich es drücken
kann.“* Am Klavier sitzend konnte sie die Tasten spielen, aber die Pedale nicht erreichen, sodass
dem Spiel der Ausdruck fehlte. Aus diesem Wunsch wurde bFaaaP.

Der allererste Prototyp **„bFaaap‑1“** (Klavierpedal‑Versuch #1, **10.02.2018**) war eine weiße,
mit Beton beschwerte Kiste voller Elektronik und Kabel — „erst einmal *irgendetwas* bauen, das sich bewegt“.
Die Originalzeichnungen — der **brillenmontierte Sensor** (eine als Design eingetragene Idee) und die
schalldichte Kammer, mit bereits vorhandenem Regelgesetz — sind, mit Handskizzen, in
[**bFaaaP 1 — wo die Erfindung begann**](history/bfaaap-1-original/README.md) gesammelt.

## Frühes Design (bFaaaP1–4)

Das frühe System bestand aus zwei Teilen, gesteuert von einem Mikrocontroller (Ära Arduino IDE,
M5Stack / ESP32; Holzgehäuse bei bFaaaP4):

- ein **Kopf‑Bewegungssensor** — eine 9‑Achsen‑IMU an einem **Brillengestell**, die die Vor/Zurück‑Bewegung des Kopfes liest, und
- ein **Aktuator** vor dem Pedal.

2018 wurde ein **internationales PCT‑Patent** angemeldet; das Verfahren (Kopfwinkel‑**Offset +
Multiplikator**, die zusammen die **Reaktionsgeschwindigkeit** festlegen) wurde später in Japan als **特許第6726319号 / 第7004771号** erteilt.

Öffentliches Debüt: ~2019 bei einem Klaviervorspiel der Klasse „Fleur“ von Kyoko Yamaguchi
(MUSICASA, Yoyogi‑Uehara).

## Der Weg bis heute

Die brillengestützte IMU wurde durch **Smartphone‑AR‑Gesichts‑Tracking (iOS‑KI)** ersetzt, das den
Kopfwinkel per **BLE** an das Pedalgerät sendet (heute ein Raspberry Pi Pico + Adafruit ItsyBitsy
nRF52840). Zwei Produktlinien entstanden:

- **Switch** — für E‑Pianos & Keyboards (elektronischer Sustain‑Buchsenschalter),
- **Pro** — für akustische Klaviere (ein Motor drückt das Haltepedal).

Aktuelle Vorführungen:

- **2024** — Kodai‑Festival, Institute of Science Tokyo (<https://www.youtube.com/watch?v=Im4jsed1tJQ>)
- **2025** — Platanus Suzukake Concert with bFaaaP (<https://www.youtube.com/watch?v=V3cXeNW9jXY>)

## Menschen

Entwickelt von den bFaaaP‑/**Platanus**‑Mitgliedern:

- **Tomoyuki Shishido** — iOS‑App
- **Hiroyuki Narusawa** — Pedalgerät / Firmware
- **Masahiro Ootaki** — Architekt; Design & Gesamtkoordination
- **Kyoko Yamaguchi**, **Daisuke Tokushige** u. a.

> Das Ziel: ein **inklusives** Design, damit **alle** — Menschen mit Gliedmaßen‑Behinderungen,
> kleine Kinder, ältere Menschen — das Klavier mit Pedal genießen können.

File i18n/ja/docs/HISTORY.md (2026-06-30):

# bFaaaP —— プロジェクトの歴史

> 🌐 [English](../../../docs/HISTORY.md) · **日本語** · [Deutsch](../../de/docs/HISTORY.md)

Platanus with bFaaaP ポスター

*bFaaaP = **b**arrier‑**F**ree **a**ssist **a**s **a** **P**edal —— AI補助ピアノ・ペダルシステム。
プロジェクトサイト：<https://bfaaap.com>*

## 始まり（2018年）

bFaaaP は **2018年1月**に始まりました。建築家**大瀧雅寛**さんの依頼主である**車椅子ユーザー**が、こう尋ねたのです ——
*「ピアノのペダルを電動化して、自分で踏めるようにしたい。」* 車椅子でピアノに向かい鍵盤は弾けても、ペダルには届かず、
演奏に表現が欠けていました。その願いが bFaaaP になりました。

最初の試作機 **「bFaaap‑1」**（ピアノ・ペダル試作#1、**2018年2月10日**）は、コンクリートで重しをした白い箱に電子部品と
配線を詰め込んだもの —— 「まず*動く何か*を作る」。当時のオリジナル図面 —— **メガネ装着型センサー**（意匠登録された
アイデア）と防音チャンバー、すでに制御則が入っている —— を、手描きスケッチとともに
[**bFaaaP 1 — 発明が始まった場所**](history/bfaaap-1-original/README.md) に収めました。

## 初期設計（bFaaaP1〜4）

初期システムはマイコン（Arduino IDE、M5Stack / ESP32 の時代。bFaaaP4 は木製筐体）で制御する2つの部分から成りました：

- **頭部モーションセンサー** —— **眼鏡フレーム**に載せた9軸IMUで、頭の前後の動きを読む、そして
- ペダルの前に置く**アクチュエータ**。

**PCT国際特許**を2018年に出願し、この方式（頭部角度の**オフセット＋乗数**、これらが**応答速度**を決める）は後に日本で
**特許第6726319号 / 第7004771号**として成立しました。

公開デビューは2019年ごろ、山口恭子さんのクラス「フルール」のピアノ発表会（ムジカーザ、代々木上原）。

## 今への歩み

眼鏡型IMUは **スマートフォンのAR顔トラッキング（iOSのAI）** に置き換わり、頭の角度を **BLE** でペダル装置
（現在は Raspberry Pi Pico ＋ Adafruit ItsyBitsy nRF52840）へ送ります。2つの製品系列が生まれました：

- **Switch** —— 電子ピアノ・キーボード向け（電子サステイン端子スイッチ）、
- **Pro** —— アコースティックピアノ向け（モーターがサステインペダルを押す）。

最近のデモ：

- **2024年** —— 工大祭、東京科学大学（<https://www.youtube.com/watch?v=Im4jsed1tJQ>）
- **2025年** —— プラタナスすずかけコンサート with bFaaaP（<https://www.youtube.com/watch?v=V3cXeNW9jXY>）

## 人々

bFaaaP / **Platanus** のメンバーによる開発：

- **宍戸 知行** —— iOSアプリ
- **成澤 博行** —— ペダル装置／ファームウェア
- **大瀧 雅寛** —— 建築家；デザイン＆全体調整
- **山口 恭子**、**徳重 大輔** ほか

> 目標：手足に障害のある方・小さな子ども・高齢の方など**誰もが**ペダルとともにピアノを楽しめる、
> **インクルーシブ**な design にすること。

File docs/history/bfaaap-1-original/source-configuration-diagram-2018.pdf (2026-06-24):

DETECTOR SIDE | ACTUATOR SIDE

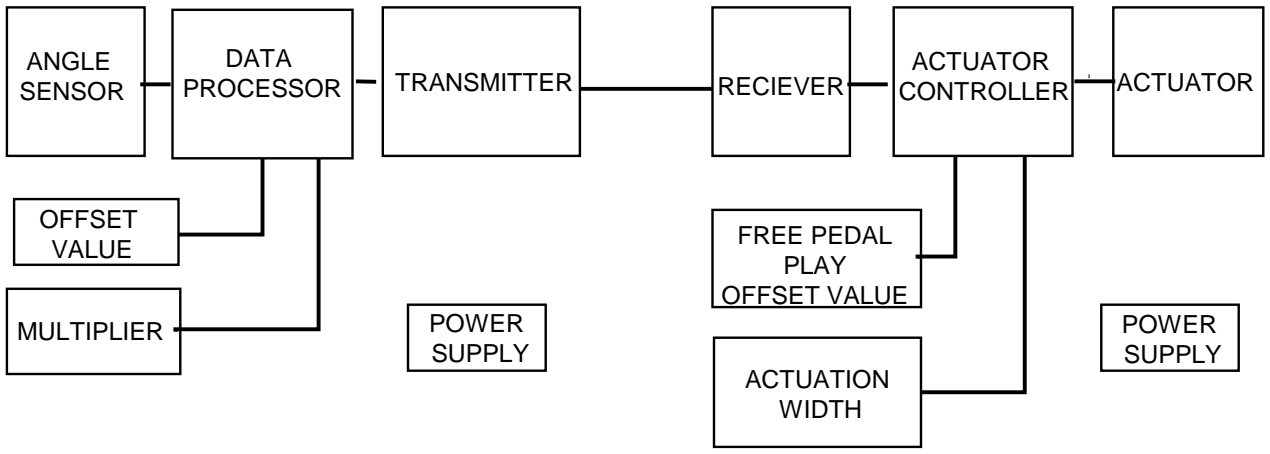
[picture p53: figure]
ACTUATOR; RECIEVER; CONTROLLER; DATA; PROCESSOR; TRANSMITTER; ANGLE SENSOR; ACTUATION WIDTH; POWER SUPPLY; MULTIPLIER; OFFSET VALUE; FREE PEDAL PLAY OFFSET VALUE

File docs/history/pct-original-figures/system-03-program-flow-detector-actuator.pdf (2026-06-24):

Detector-side Program 1 (Pitch Angle)

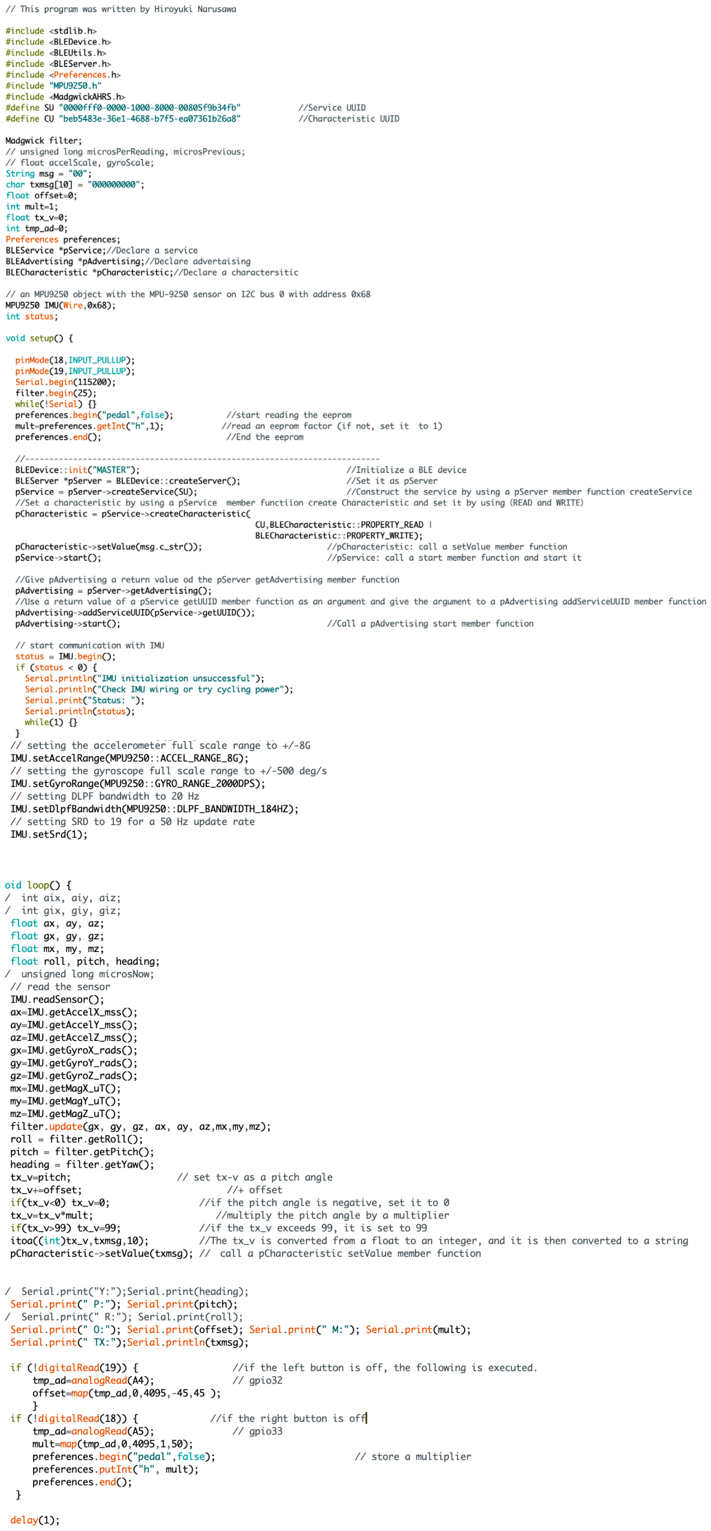
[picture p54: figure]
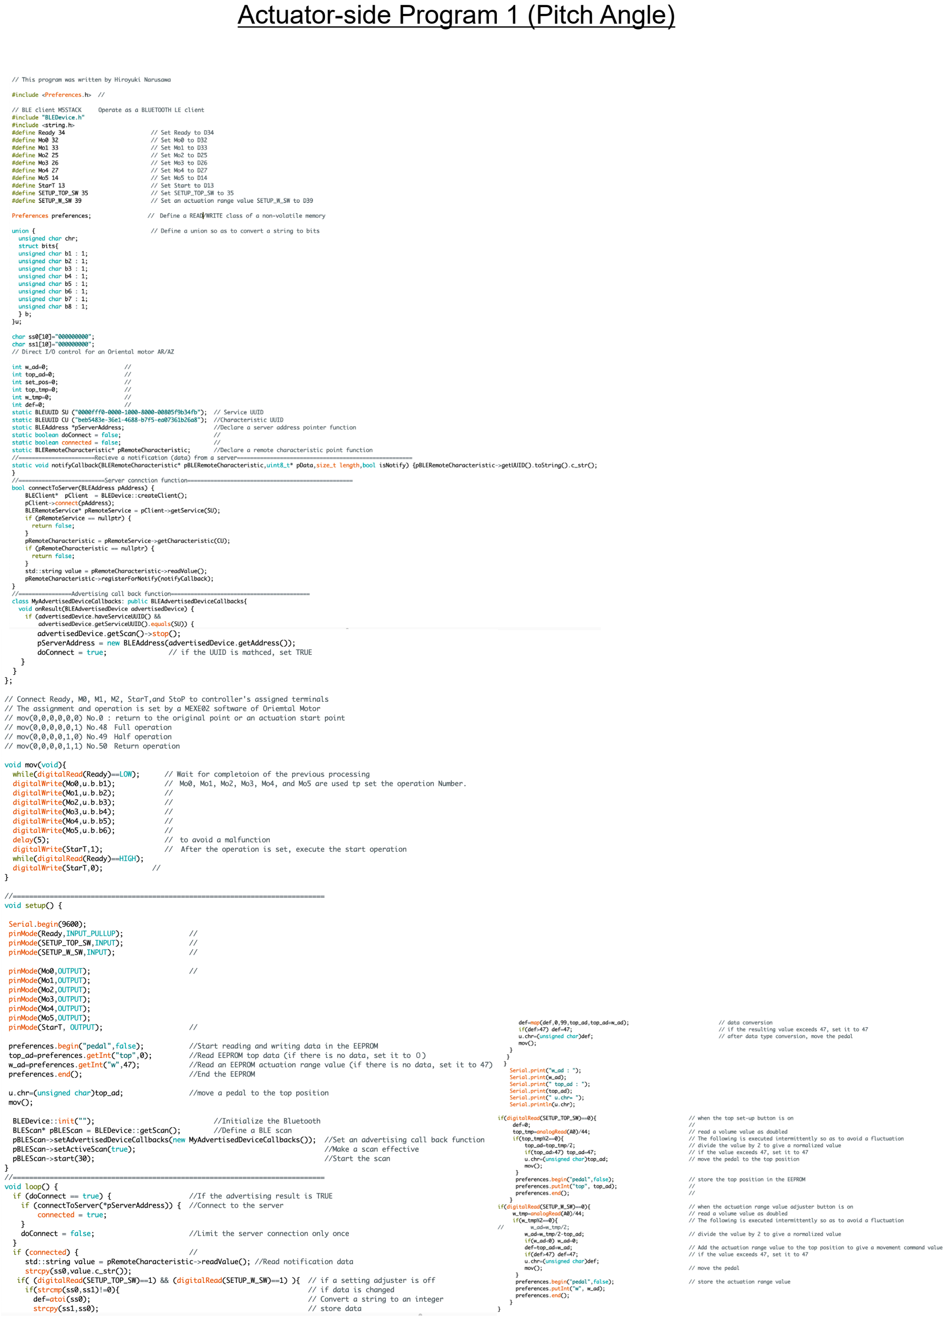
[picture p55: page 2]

Actuator-side Program 1 (Pitch Angle)

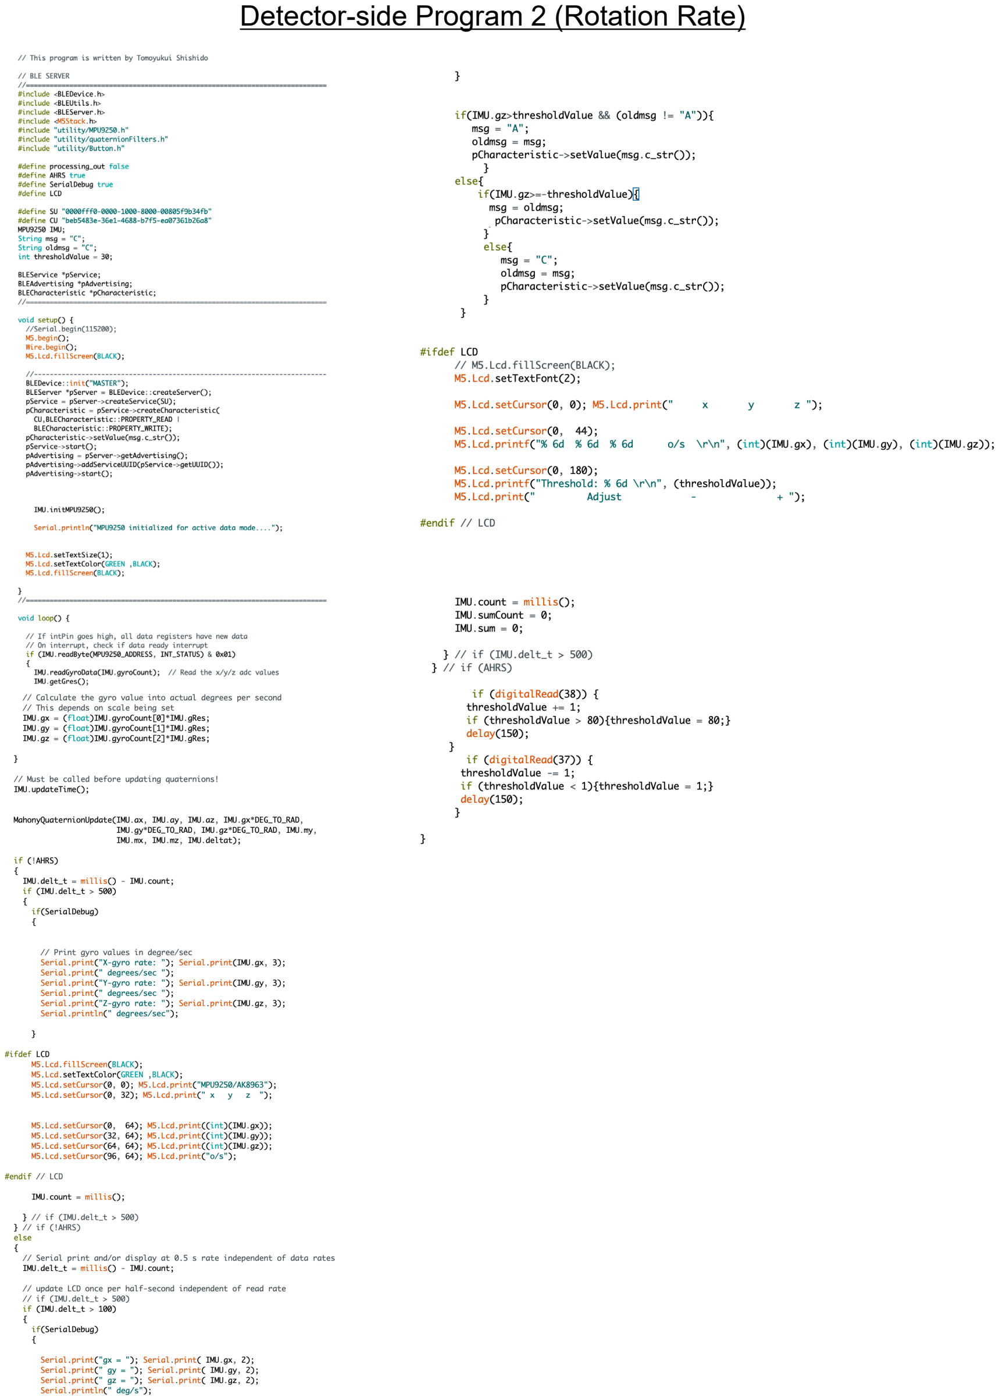
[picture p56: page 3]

Detector-side Program 2 (Rotation Rate)

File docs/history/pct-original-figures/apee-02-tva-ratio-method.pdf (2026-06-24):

FIG. 25

A.

B.

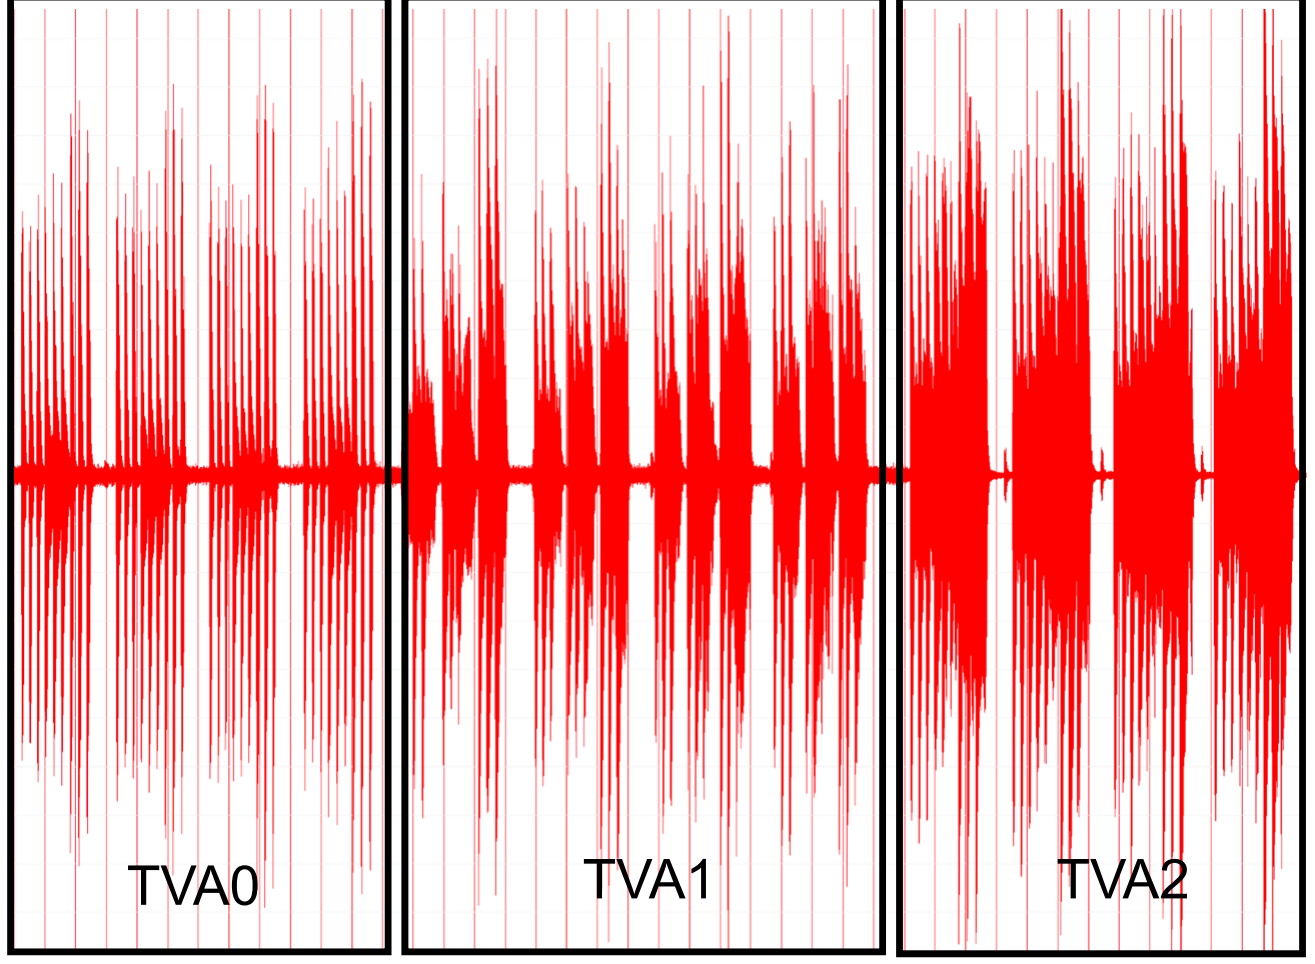
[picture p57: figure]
TVA0; TVA1; TVA2

TVA0 IS SET TO 1
RATIO (PEDAL PATTERN 1) = TVA1 / TVA0 RATIO (PEDAL PATTERN 2) = TVA2 / TVA0

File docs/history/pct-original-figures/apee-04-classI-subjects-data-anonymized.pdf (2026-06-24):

## Auxiliary Pedal Effect Evaluation Study (APEE study)

Pattern 0 | Pattern 1 | Pattern 2
No.1 | 2018/8/26 | 50 | 1 to 2 years (when he was a child) | K132 | Regular Pedal | N.A. | N.A. | 1.00 | 1.26 | 1.81 | 1
| | | | | bFaaaP2 (M5Stack) | 5 | 15 | 1.00 | 1.05 | 1.26 | 2
| | | | | bFaaP3 | N.D. | N.D. | 1.00 | 1.15 | 1.27 | 3
No. 2 | 2018/9/19 | 66 | 0 years | K132 | bFaaaP4 | 19 | 29 | 1.00 | 1.86 | 3.30 | 4
No. 3 | 2018/9/19 | 53 | 0 years | K132 | bFaaaP4 | 10 | 30 | 1.00 | 1.41 | 1.78 | 5
| 2018/10/7 | | | UX | Regular Pedal | N.A. | N.A. | 1.00 | 1.29 | 1.31 | 6
| | | | | bFaaaP4 | 15 | 25 | 1.00 | 1.30 | 1.58 | 7
| | | | | | 10 | 40 | 1.00 | 1.25 | 1.45 | 8
| 2018/10/31 | | | K132 | Regular Pedal | N.A. | N.A. | 1.00 | 1.29 | 1.51 | 9
| 2018/10/31 | | | GP1 | bFaaaP4W | 5 | 20 | 1.00 | 1.67 | 1.97 | 10
| | | | | | 5 | 30 | 1.00 | 1.70 | 1.78 | 11
| | | | | Regular Pedal | N.A. | N.A. | 1.00 | 1.41 | 1.41 | 12
No. 4 | 2018/9/23 | 48 | Many years | K132 | bFaaaP4 | 5 | 20 | 1.00 | 1.77 | 1.97 | 13
| | | | | | 10 | 20 | 1.00 | 1.63 | 1.70 | 14
| | | | | | 5 | 40 | 1.00 | 1.80 | 1.94 | 15
| | | | | Regular Pedal | N.A. | N.A. | 1.00 | 1.90 | 2.46 | 16
No. 5 | 2018/9/27 | 35 | Many years | K132 | bFaaaP4 | 10 | 30 | 1.00 | 1.64 | 1.83 | 17
| | | | | | 15 | 30 | 1.00 | 1.73 | 1.83 | 18
| | | | | Regular Pedal | N.A. | N.A. | 1.00 | 1.92 | 2.06 | 19
| 2018/10/31 | | | GP1 | bFaaaP4W | 5 | 20 | 1.00 | 1.94 | 1.97 | 20
| | | | | | 5 | 30 | 1.00 | 1.82 | 1.93 | 21
| | | | | Regular Pedal | N.A. | N.A. | 1.00 | 1.88 | 2.20 | 22
No. 6 | 2018/10/7 | In her teens | 3 years | UX 2018/10/8 | Regular Pedal | N.A. | N.A. | 1.00 | 1.18 | 1.45 | 23
| | | | | bFaaaP4 | 5 | 10 | 1.00 | 1.43 | 1.48 | 24
| | | | | | 10 | 30 | 1.00 | 1.19 | 1.28 | 25
No. 7 | 2018/10/7 | In her fourties | 6 years | UX | Regular Pedal | N.A. | N.A. | 1.00 | 1.08 | 1.06 | 26
| | | | | bFaaaP4 | 10 | 30 | 1.00 | 1.27 | 1.27 | 27
| | | | | | 5 | 10 | 1.00 | 1.12 | 1.17 | 28

Class I (adults)

Device
(with or w/o bFaaaaP) | Offset Value | Multiplier | Test No. Tone-vibrating Area (TVA) Relative to Pattern 0 Subject Class | Subject Number | Test Date | Age | Piano Experience | Piano

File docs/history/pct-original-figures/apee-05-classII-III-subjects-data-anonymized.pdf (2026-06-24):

## Auxiliary Pedal Effect Evaluation Study (APEE study)

Pattern 0 | Pattern 1 | Pattern 2
Class II (kids) | No. 8 | 2018/10/31 | 11 | 2 years and 7 months | GP1 | bFaaaP4W | 5 | 20 | 1.00 | 1.83 | 2.19 | 29
| | | | | | | 5 | 30 | 1.00 | 2.05 | 2.23 | 30
| No. 9 | 2018/10/31 | 8 | 1 year and 6 months | GP1 | bFaaaP4W | 5 | 20 | 1.00 | 1.87 | 1.78 | 31
| | | | | | | 5 | 30 | 1.00 | 1.19 | 1.01 | 32
| No. 10 | 2018/10/31 | 10 | 5 years | GP1 | bFaaaP4W | 5 | 20 | 1.00 | 2.17 | 2.42 | 33
| | | | | | | 5 | 30 | 1.00 | 1.66 | 1.75 | 34
| No. 11 | 2018/10/31 | 8 | 2 years | GP1 | bFaaaP4W | 5 | 20 | 1.00 | 2.18 | 2.57 | 35
| | | | | | | 5 | 30 | 1.00 | 1.56 | 1.56 | 36
| No. 12 | 2018/10/31 | 7 | 2 years | GP1 | bFaaaP4W | 5 | 20 | 1.00 | 2.06 | 1.89 | 37
| | | | | | | 5 | 30 | 1.00 | 1.23 | 1.68 | 38
Class III (the challenged) | No. 13 (with leg disabilities) | 2018/8/26 | 16 | 0 years | K132 | BFaaaP2 (M5Stack) | 10 | 15 | 1.00 | 1.09 | 0.90 | 39
| | | | | | bFaaaP3 | N.D. | N.D. | 1.00 | 1.32 | 1.30 | 40
| No. 14 (with partial leg disabilities and tracheotomy) | 2018/9/23 | 19 | Several years | K132 | bFaaaP4 | 5 | 40 | 1.00 | 1.18 | 1.36 | 41
| | | | | | | 3 | 50 (Max) | 1.00 | 0.98 | 1.67 | 42
| No. 15 (with leg disabilites) | 2018/8/5 | 50 | 5 years | K132 | bFaaaP2 (M5Stack) | 5 | 8 | 1.00 | 1.72 | 2.12 | 43
| | 2018/9/19 | | | | bFaaaP4 | 10 | 30 | 1.00 | 1.84 | 2.22 | 44
| | 2018/9/23 | | | | | 10 | 40 | 1.00 | 1.70 | 1.79 | 45
| | 2018/9/27 | | | | | 5 | 40 | 1.00 | 1.56 | 2.17 | 46
Offset Value | Multiplier | Test No. Tone-vibrating Area (TVA)
Relative to Pattern 0
Subject Class | Subject Number | Test Date | Age | Piano Experience
Piano | Device
(with or w/o bFaaaaP)

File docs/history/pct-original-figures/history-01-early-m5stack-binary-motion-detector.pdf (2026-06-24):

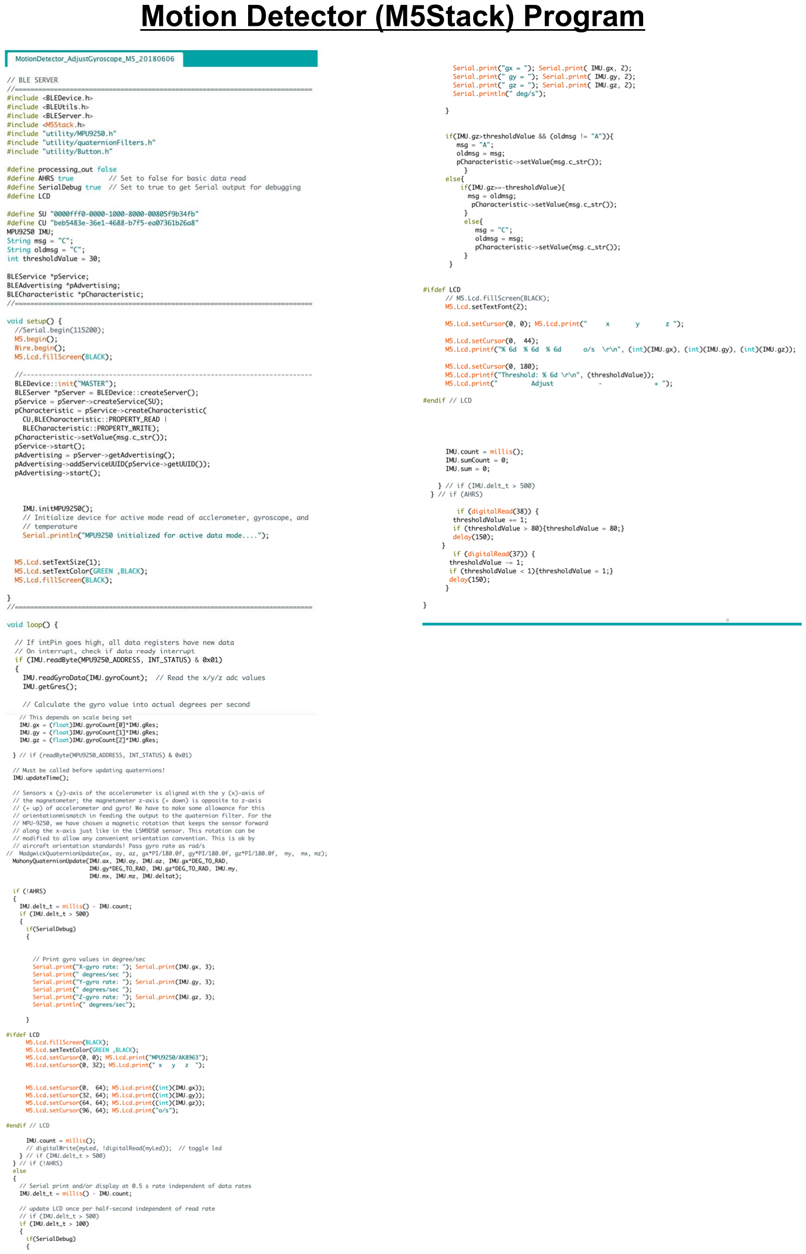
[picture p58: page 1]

Motion Detector (M5Stack) Program

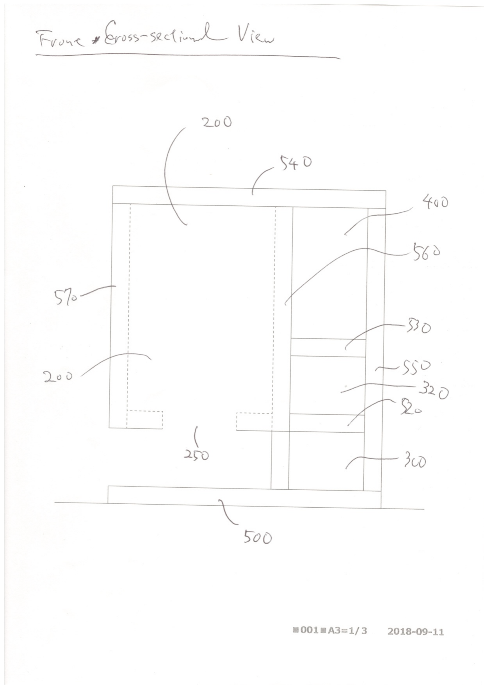
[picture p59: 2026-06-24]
docs/history/bfaaap-1-original/handdrawn-front-cross-section.png

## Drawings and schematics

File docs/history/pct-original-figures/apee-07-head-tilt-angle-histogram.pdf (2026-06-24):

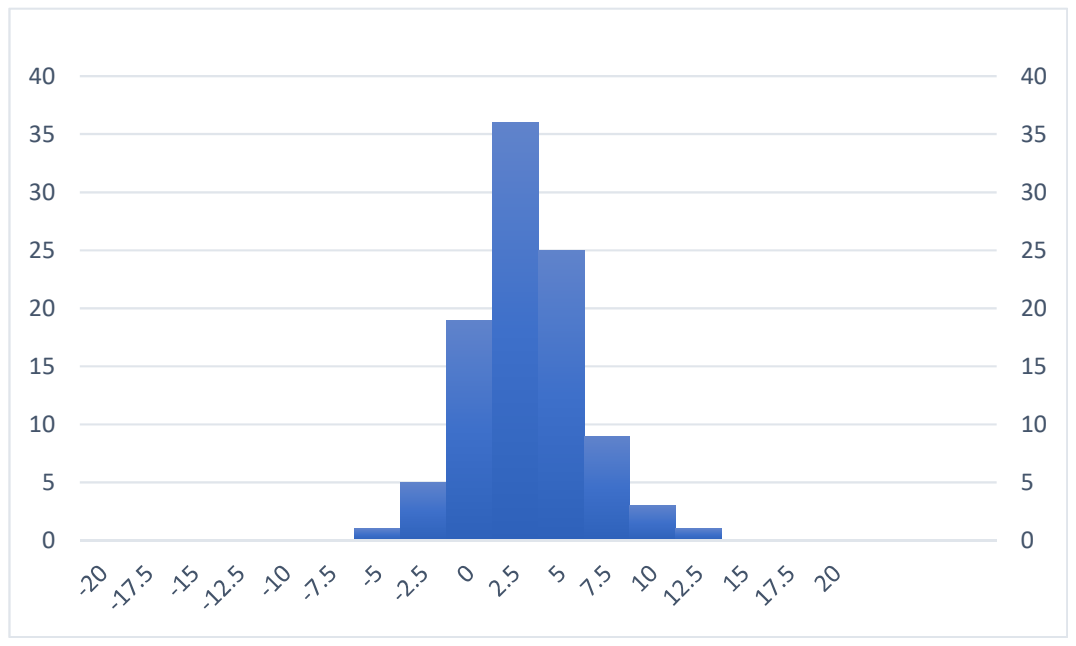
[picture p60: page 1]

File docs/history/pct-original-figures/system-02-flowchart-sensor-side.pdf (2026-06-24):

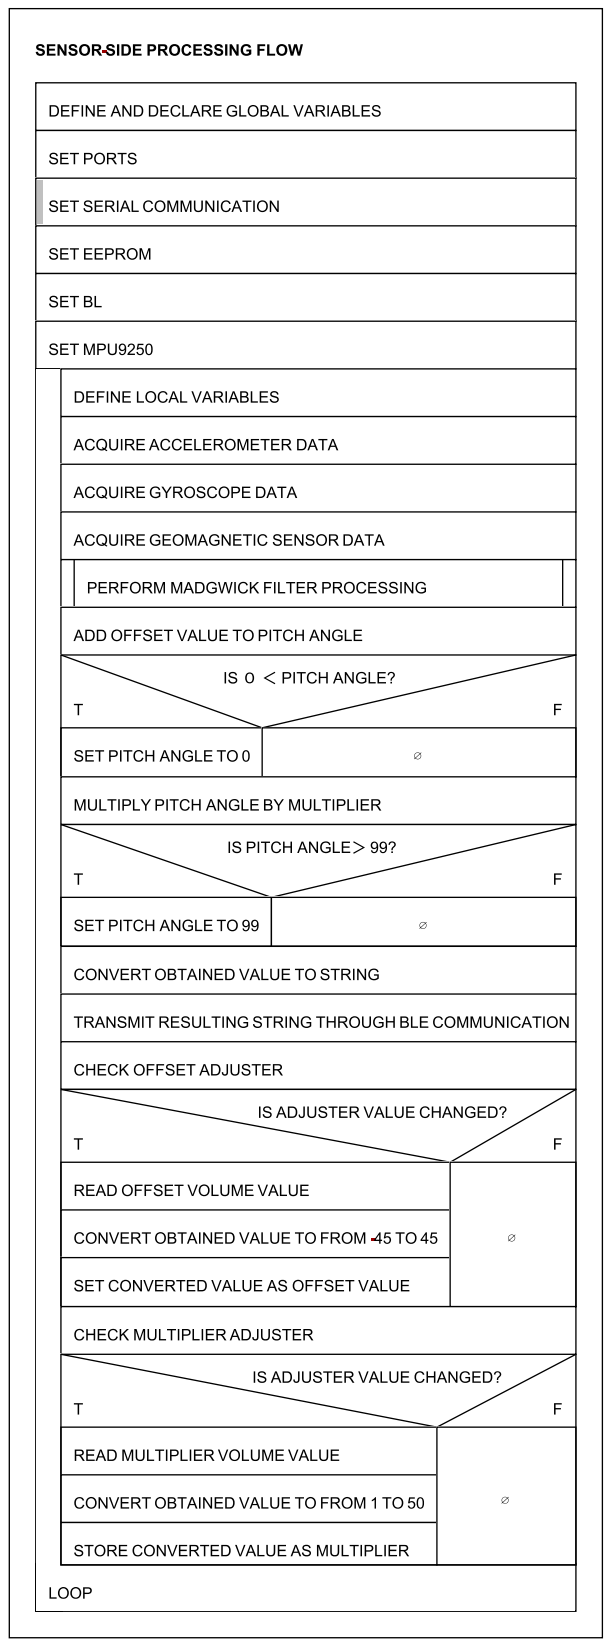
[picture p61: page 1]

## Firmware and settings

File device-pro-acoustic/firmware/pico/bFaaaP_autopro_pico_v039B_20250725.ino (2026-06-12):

/*
bFaaaP_autopro_v039B_20250725 for raspberry pi pico or pico2
prog. by Hiroyuki Narusawa
2025/07/25

// raspberry pi pico or raspberry pi pico2
Serial                        for USB
Serial1 TX1/GP00 RX1/GP01　　　for BLEデータ   1pin 2pin
Serial2 TX2/GP04 RX2/GP05　　　for IQモーター　 6pin 7pin  
I2C.    SDA/GP02 SCL/GP03.    for 圧力センサー　HX711 4pin 5pin
GPIO.   OUTPUT.     /GP12     for MOSFET 駆動ポート　

// IQ Motor 端子
         12-48V
          ^ ^
          | |
          | | 
          - +
        G | |
o o o o o o o
        o tx -----> RX1
        o rx <----- TX1

*/

#include <iq_module_communication.hpp> //
#include "HX711.h"
float   mm=PI/8;         // １ｍｍ動くための回転角度（ラジアン）一回転8mm
float   cu_rad=0;        // current positon　現在の回転角度
uint8_t vol=30;          // Buzzer saund levelブザーの音量値セット
int     def=0;           // 差分値
int     tmp=0;           //
int     incomingByte = 0;// for incoming bluteeth serial data
float   pos=0;           //
float   up_pos=0;        //機械的上限値
float   down_pos=0;      //機械的下限値
float   upoffset=0;
float   downoffset=10;
float   downforce=20;
float   tmp_uos=0;
float   def_ad=0;
float   orig_pos=0;
float   move_pos=0;
// Define the pins for the HX711 communication(I2C)
const int LOADCELL_DOUT_PIN = 2;
const int LOADCELL_SCK_PIN = 3;

HX711 scale;



IqSerial ser(Serial2);               //IQ motor シリアルポート付き　定義
MultiTurnAngleControlClient mult(0); //IQ motorの多回転角度制御　　クライアント名定義
BuzzerControlClient buz(0);          //IQ motorのブザー制御　　　　クライアント名定義
PowerMonitorClient pwr(0);           //IQ motorの電力モニター制御　クライアント名定義

//　モーターから周波数(hz)の発振音をlen（ms）間出す
void booo(uint16_t hz,uint16_t len) {

    ser.set(buz.hz_,hz);        //　周波数
    ser.set(buz.volume_,vol);   //　音量
    ser.set(buz.duration_,len); //　継続時間
    ser.set(buz.ctrl_note_);    //　スタート
    delay(len);                 //　継続時間だけ待つ
}
/*
void move(float mov,float dur){// mov 回転角　dur 所要時間
    ser.set(mult.trajectory_angular_displacement_,mov);// 回転角セット
    dur=abs(mov-move_pos)/20*0.1;
    ser.set(mult.trajectory_duration_,dur);//　回転所要時間セットと回転の開始　実際に回転し始める
    move_pos=mov;
}
*/
void move(float mov,float dur){// mov 回転角　dur 所要時間
    ser.set(mult.trajectory_angular_displacement_,mov);// 回転角セット
    ser.set(mult.trajectory_duration_,dur);//　回転所要時間セットと回転の開始　実際に回転し始める
}
float nibble_float(int gpio_no){
      int tmp=0;
      float ftmp=0;
      tmp=digitalRead(gpio_no);
      if(tmp==0){
        ftmp=ftmp+8.0;
      }
      tmp=digitalRead(gpio_no+1);
      if(tmp==0){ 
        ftmp+=4.0;
      }
      tmp=digitalRead(gpio_no+2);
      if(tmp==0){
        ftmp+=2.0;        
      }
      tmp=digitalRead(gpio_no+3);
      if(tmp==0){
        ftmp+=1.0;        
      }
      return(ftmp);
}
// ペダル位置の自動セット
void auto_set(void){
    float mmm=-mm;
    float cu=cu_rad;
    float watt=0;
    //float down_limt=0;
    int   c=0;
    //ser.get(mult.obs_angular_displacement_,cu_rad);
    ser.get(pwr.watts_,watt);
    Serial.print("watt="); Serial.println(watt);
    // Serial.print(""); Serial.printnl();
    // 駆動電力が１０W以下の間、続ける　1mmずつ上げる
    //物理的に突き当たり駆動しようとして電力が増加する         
    while(watt<10){ 
          move(cu+mmm,0.1f);
          delay(110);
          mmm-=mm;
          ser.get(pwr.watts_,watt);
          Serial.print("watt="); Serial.println(watt);
    }
    Serial.println("auto_up_pos_set_end");
    mmm+=5*mm; // 突き当たっているので５mm下げる
    move(cu+mmm,0.5f);
    delay(510);
    up_pos=cu+mmm;
//    down_limt=up_pos+mm*50;
//    down_limt=mmm+50*mm;
//  駆動電力が3０W以下か下りが50mm以下の間、1mmずつ下げを続ける　
//  物理的に突き当たり駆動しようとして電力が増加する　50mm以上下げると押し棒が抜ける
//    while((watt<30) || ((cu+mmm)<down_limt)){

//　押さえつける力が強すぎると、滑るので、watt数を２０に変更　まだ検討の余地あり　ピアノによって変わる
// 場合によっては、本体に設定スイッチもしくはpinが必要になるかも
// 2025/07/21 ２０wでは弱すぎて突き当たる前に動作する
// 2025/07/22 ディップスイッチにて押さえ込む力（電力値）を設定出来る様にした
// ディップスイッチの値＋２０Wとし２０Wから３５Wまで１W単位で設定
// 2025/07/22 ディップスイッチで突き当たり点より上げる値を5-20mm設定できる様にした 

    downforce=nibble_float(14)+20;
    ser.get(pwr.watts_,watt);
    while((watt<downforce)){ 
          move(cu+mmm,0.1f);
          delay(110);
          mmm+=mm;
          c++;
          if(c>65) break;
          ser.get(pwr.watts_,watt);
          Serial.print("watt="); Serial.println(watt);         
  //        Serial.print("down_limt="); Serial.println(down_limt);
          Serial.print("cu+mmm="); Serial.println(cu+mmm);
  //        Serial.print("watt="); Serial.println(watt);
    }
    Serial.println("auto_down_pos_set_end");
    downoffset=nibble_float(18)+5;
    mmm-=downoffset*mm;       // 突き当たっているのディップスイッチ設定値＋５mm上げる
    move(cu+mmm,0.1f);
    delay(110);
    down_pos=cu+mmm;
    move(up_pos,0.5f);
    Serial.println("auto_set_end");
    delay(510);
}

// map関数の浮動小数化関数
float mapf(float x, float in_min, float in_max, float out_min, float out_max) {
      return (x - in_min) * (out_max - out_min) / (in_max - in_min) + out_min;
}

//エアージャッキによる装置の固定
void auto_air_jack(void){
  long p=0;
  unsigned long tt=0;
  p=scale.read();
  if(p<6000000){  //空気圧が足らない間、空気を送る
     tt=millis();
     digitalWrite(12,1); //
     p=scale.read();
     while(p<8000000){   //空気圧が足らない状態が３０秒続いたら中止
      if(millis()-tt>30000){
         Serial.println("timeout 30Sec");
         break;
      }
      Serial.println(p); 
      p=scale.read();
  
     }
     digitalWrite(12,0); //
     p=scale.read();
     Serial.println("hx711_end");
  }
//  Serial.print("p=");
//  Serial.println(p); 

  if(p<6000000){ //空気圧が足らないのでエラー警告音を鳴らす
    Serial.println("P_err");
    while(1){
      booo(500,1000);
      delay(1000);
      booo(1000,1000);
      delay(1000);
    }
  }
  digitalWrite(12,1);
  delay(10000);
  digitalWrite(12,0);
}

int offset_AD_read(void){
    analogReadResolution(6); // ADの解像度を５ビットとし値を0−３２にしオフセットに使用　単位mm
// 20250725 ADの解像度を6ビットとし値を0−64mmにしオフセットに使用

    int tmp=analogRead(A0);
//        tmp/=2;
        Serial.println(tmp);
    return(tmp);
}
void test_ad(void){
  while(1){
    upoffset=offset_AD_read();//
    def_ad=abs(upoffset-tmp_uos);
    if(def_ad>1){    //
      up_pos+=upoffset;       //
      tmp_uos=upoffset;       //
      Serial.print("offset_AD_read=");
      Serial.println(upoffset);
    } 
  } 
}

void test_dipsw(void){
  float ftmp=0;
    downforce=nibble_float(14)+20;
    Serial.print("downforce=");
    Serial.println(downforce);

    downoffset=nibble_float(18)+5;
    Serial.print("downoffset=");
    Serial.println(downoffset);
  delay(1000);
}

void setup() {
  float check_def=0;
  delay(5000);
  Serial1.setTX(0);                   // for IQmotor TX GP00
  Serial1.setRX(1);                   // for IQmotor RX GP01
  Serial2.setTX(4);                   // for BLE TX GP04
  Serial2.setRX(5);                   // for BLE RX GP05
  Serial.begin(115200);               // Serialボーレート指定　 for USB (debug)
  Serial1.begin(115200);
  Serial2.begin(115200);              // Serial2ボーレート指定　for BLE
  pinMode(12, OUTPUT);                // MOSFET 駆動ポート　GP12
  pinMode(14, INPUT);                // ポート　GP14 GP14-17 for downforce
  pinMode(15, INPUT);                // ポート　GP15 20w+(0-15)W
  pinMode(16, INPUT);                // ポート　GP16 min 20W
  pinMode(17, INPUT);                // ポート　GP17 max 35W
  pinMode(18, INPUT);                // ポート　GP18 GP18-21 for downoffset
  pinMode(19, INPUT);                // ポート　GP19 5mm+(0-15)mm
  pinMode(20, INPUT);                // ポート　GP20 min 5mm
  pinMode(21, INPUT);                // ポート　GP21 max 20mm
  Serial.println("bFaaaP_autopro_pico_v039B 20250725 for raspberry pi pico or 2");
  delay(100);                        // モーターのセットアップ時間の待ち時間  
// Initialize the HX711
  scale.begin(LOADCELL_DOUT_PIN, LOADCELL_SCK_PIN);
  ser.begin(115200);                  // start IQ motor 
  delay(100);

//  while(1){
//    test_dipsw();
//  }
  ser.get(mult.obs_angular_displacement_,cu_rad); // 電源投入時の回転角位置を取得
  delay(100);



  // ad_test_loop
  //test_ad();
  auto_air_jack();                    // エアージャッキで装置の固定する
  auto_set();                         // 機械的トップとダウン位置を検出後、down 10mm上げ　up 10mm下げ 
  orig_pos=up_pos;                    // この時点の上限値
  upoffset=offset_AD_read();          //　上限値設定AD値の読み込み　0−３１（mm）
  check_def=orig_pos+mm*upoffset;     //　上限値にオフセット分加える
  if(check_def<down_pos){           //　下限値と上述値を比較
     up_pos=check_def;                //　プラスなら上限値に設定値を加え新しいup_posとする
  }else{
     up_pos=down_pos-mm;              //　０かマイナスなら下限値から1mm引いた値を新しいup_posとする 
  }             
  tmp_uos=upoffset;                   //
  //move(up_pos,0.1f);
  //delay(110);
  move(up_pos,1.0f);
  delay(1100);

//  Serial.print("offset_ad_read="); Serial.println(upoffset);         
//  Serial.print("up_pos="); Serial.println(up_pos);
  // orig_pos=up_pos;
  }

//IQ Motor 最高回転数4000rpm 一秒間に67回転　一秒間で533mm（８mmリードスクリュー）50mmでほぼ　100ms 
//移動量に関わらず移動時間を90mSに固定した
//移動量と連動して移動時間を可変にする方法もある今後の課題 
void loop() {
  float check_def=0;
  if(Serial1.available() > 0) {                          // read the incoming byte:　BLEからデータが送られている場合
    incomingByte= Serial1.read();                        // データを読む
//    Serial.print("incomingByte="); Serial.println(incomingByte);
    pos=mapf((float)incomingByte,0,99,up_pos,down_pos);  // BLEから送られて来る０－９９の値をup_pos,down_posの間にマッピング
    def=incomingByte-tmp;                                // 首のブレを考慮して送られて来るデータに２以上の差が有る場合に動作
    def=abs(def);                                        //　差分の絶対値を計算
    if(def>2){                                           //　2以上なら駆動する   
      move(pos,0.09f);                                   //  ９０ｍｓでＰＯＳ位置まで移動
      delay(100);                                        //　１００ｍｓ駆動時間を待つ
      tmp=incomingByte;                                  //　前回との比較のために今回の値を記憶  
    }
    upoffset=offset_AD_read();                           //
    def_ad=abs(upoffset-tmp_uos);
    check_def=orig_pos+mm*upoffset;                        
    if(def_ad>1){                                        //
       if(check_def<down_pos)                            //　下限値より上限設定値が大きい場合
          up_pos=orig_pos+mm*upoffset;
       else
          up_pos=down_pos-mm;                            //　０かマイナスなら下限値から1mm引いた値を新しいup_posとする
      tmp_uos=upoffset;                                  //
//      Serial.print("offset_AD_read=");
//      Serial.println(upoffset);
    }  
  }

}

//
//    APPENDIX   APPENDIX   APPENDIX   APPENDIX   APPENDIX   APPENDIX   APPENDIX   APPENDIX   APPENDIX

/* IQモーターのマルチターンアングルコントローラークラスのファンクション表
　　ファンクション名の末尾にアンダーバーを付けて使用する
（ 例 ) trajectory_angular_displacementとtrajectory_duration の場合

　　　#include <iq_module_communication.hpp>    // include
                      .
　　　MultiTurnAngleControlClient mult(0);      //
                      .
　　　IqSerial ser(Serial1);                    // uart 指定
                      .
　　　ser.set(mult.trajectory_angular_displacement_,mov);// 回転角セット
　　　ser.set(mult.trajectory_duration_,dur);//　所要時間セットと回転の開始　実際に回転し始める

この5行だけで所定、回転角位置に回転し停止する、外部から力が加わっても位置を維持しようとする

Type ID 59 | Multi-turn Angle Controller
SubID  ShortName                       Access          DataType  Unit        Note
    0  ctrl_mode                       get.            int8      enum        no_change = -1, brake=0, coast=1, pwm=2, volts=3, velocity=4, angle=5, trajectory=6
    1  ctrl_brake                      set.                                  Shorts motor phases, slows motor down dissipating energy in motor
    2  ctrl_coast                      set.                                  Disables all drive circuitry, motor passively coasts
    3. ctrl_angle                      get, set        float     rad.        Angular location command
    4. ctrl_velocity                   get, set.       float.    rad/s.      Angular velocity command
    5  angle_Kp.                       get, set, save  float.    V/rad       Proportional gain
    6  angle_Ki.                       get, set, save  float.    V/(rad*s).  Integral gain
    7. angle_Kd                        get, set, save. float.    V/(rad/s).  Derivative gain
    8. timeout.                        get, set, save. float.    s.          The controller must receive a message within this time otherwise it is set to coast mode
    9. ctrl_pwm.                       get, set.       float.    PWM.        Spins motor with this throttle [-1, 1]
   10  ctrl_volts.                     get, set        float     V.          Spins motor with this voltage
   11  obs_angular_displacement        get, set        float.    rad.        Observed angular location
   12. obs_angular_velocity.           get             float.    rad/s.      Observed angular velocity
   13. meter_per_rad.                  get, set, save. float.    m/rad.      Transmission between angular and linear motion
   14  ctrl_linear_displacement.       get, set,       float.    m.          Linear equivalent to ctrl_angle
   15  ctrl_linear_velocity.           get, set,       float.    m/s.        Linear equivalent to ctrl_velocity
   16. obs_linear_displacement.        get, set,       float.    m.          Observed linear location
   17. obs_linear_velocity.            get.            float.    m/s.        Observed linear velocity
   18. angular_speed_max.              get, set, save. float.    rad/s.      The controller will never attempt to exceed this speed
   19. trajectory_angular_displacement get, set        float.    rad.        Final absolute displacement of trajectory.
   20. trajectory_angular_velocity.    get, set.       float.    rad/s.      Final velocity of the trajectory. Defaults to 0.
   21. trajectory_angular_acceleration get, set.       float.                Final acceleration of the trajectory. Defaults to 0.
   22. trajectory_duration.            set.            float.    s.          Duration of trajectory. Trajectory is executed or queued once this is sent.
   23. trajectory_linear_displacement  get, set.       float.    m.          Final absolute displacement of trajectory.
   24. trajectory_linear_velocity      get, set.       float.    m/s.        Final velocity of the trajectory. Defaults to 0.
   25. trajectory_linear_acceleration  get, set.       float.                Final acceleration of the trajectory. Defaults to 0.
   26. trajectory_average_speed.       get, set.       float                 Average speed of a trajectory. Trajectory is executed or queued once this is sent. Must be $>0$.
   27. trajectory_queue_mode.          get, set, save. int8.                 append=0, overwrite=1
   29. ff                              get, set        uint32.               Feed forward term
   30  sample_zero_angle               set. Sets                             the module’s current postiion as the zero angle.
   31. zero_angle.                     get, set, save. float.    rad.        The anglular position that the module considers as its ‘zero’ position.

*/
/*IQモーターのパワーセーフティークラスのファンクション表
ファンクション名の末尾にアンダーバーを付けて使用する
（ 例 ) PowerMonitorClient
#include <iq_module_communication.hpp>    // include
PowerMonitorClient pwr(0);
IqSerial ser(Serial1);                    // uart 指定
ser.get(pwr.watts_,watt);                 // 現在の入力電力



Type ID 84 | Power Safety
Power Safety
Sub ID    Short Name           Access.       Data Type   Unit.           Note

0.       fault_now.         get.              uint8.               The fault(s) that are currently triggering

1.       fault_ever         get, set, save.   uint8.               Record of all faults that were triggered since last modified by user. The user can clear all of the records by setting the value to 0, or individual faults by properly setting bitmask value

2.      fault_latching.     get, set, save.   uint8.               Determines if the motor is latching. When latching, if there are any bits set in fault_ever, motor will stay in Safe Mode until they are cleared. When not latching, motor will enter and exit Safe Mode only on current faults based on fault_now

3.      volt_input_low.     get, set, save.   float.               Minimum threshold value for voltage

4.      volt_input_high.    get, set, save.   float.               Maximum threshold value for voltage

5.      vref_int_low.       get, set, save.   float.               Minimum threshold value for reference voltage

6.      vref_int_high.      get, set, save.   float.               Maximum threshold value for reference voltage

7.    current_input_low.    get, set, save.   float.               Minimum threshold value for current

8.    current_input_high.   get, set, save.   float.               Maximum threshold value for current

9.    motor_current_low.    get, set, save.   float.               Minimum threshold value for motor current

10.   motor_current_high.   get, set, save.   float.               Maximum threshold value for motor current

11.   temperature_uc_low.   get, set, save.   float.               Minimum threshold value for microcontroller temperature

12.   temperature_uc_high   get, set, save.   float.               Maximum threshold value for microcontroller temperature

13.   temperature_coil_low. get, set, save.   float                Minimum threshold value for coil temperature

14.   temperature_coil_high get, set, save.   float.               Maximum threshold value for coil temperature


*/

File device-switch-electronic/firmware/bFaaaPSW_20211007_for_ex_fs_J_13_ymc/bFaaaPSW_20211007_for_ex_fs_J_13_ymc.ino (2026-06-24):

/*********************************************************************

// UUIDs:6e400001-b5a3-f393-e0a9-e50e24dcca9e
// UUIDc:6e400002-b5a3-f393-e0a9-e50e24dcca9e

*********************************************************************/

#include <bluefruit.h>
#include <Adafruit_LittleFS.h>
#include <InternalFileSystem.h>
#include <Adafruit_DotStar.h>
#include <stdio.h>
#include <string>
#define WAKE_LOW_PIN  PIN_A1
#define WST       "/W.txt"

// There is only one pixel on the board
#define NUMPIXELS 1 
#define DATAPIN    8
#define CLOCKPIN   6
#define on   0
#define off  1

using namespace Adafruit_LittleFS_Namespace;

uint32_t       color=0x000000;      // 'On' color (starts red)

/*
B=0x000000;
b=0x0000ff;
r=0x00ff00;
m=0x00ffff;
g=0xff0000;
c=0xff00ff;
y=0xffff00;
w=0xffffff;
uint32_t y=0xb4f633; 
uint32_t g=0x844624; 
uint32_t m=0x00923b;
*/
uint32_t y=0x0000ff; 
uint32_t g=0xff0000; 
uint32_t m=0x00923b;


char ad_name[4][15]={"bFaaaPSwitch_1","bFaaaPSwitch_2","bFaaaPSwitch_3","bFaaaPSwitch_4"};                    
int               n=0;
int               c=0;
int               rr=1;
unsigned long     tt;
int               b=1;
int               f=0;
unsigned long     btmp=0;
String            Model("pFaaaPSwitch");

Adafruit_DotStar strip(NUMPIXELS, DATAPIN, CLOCKPIN, DOTSTAR_BRG);

File file(InternalFS);

// BLE Service
BLEDfu  bledfu;  // OTA DFU service
BLEDis  bledis;  // device information
BLEUart bleuart; // uart over ble
BLEBas  blebas;  // battery

void setup()
{
  uint32_t readlen;
  char buffer[15]={0}; 
  char buffer2[1000]={0};  
  int i;

  #if CFG_DEBUG
      // Blocking wait for connection when debug mode is enabled via IDE
      while ( !Serial ) yield();
  #endif
  
  pinMode(13, OUTPUT);
  pinMode(A1, INPUT_PULLUP);
//  Serial.begin(115200);
//  while ( !Serial ) delay(10);   // for nrf52840 with native usb

  tt=millis();
  btmp=tt+500;
  tt=tt+30000; 
  // setup for DOTSTAR  
  strip.begin(); // Initialize pins for output
  strip.setBrightness(100);
  LED(off,g);
  LED(on,y);

  Bluefruit.autoConnLed(false); //true/false
  
  // Config the peripheral connection with maximum bandwidth 
  // more SRAM required by SoftDevice
  // Note: All config***() function must be called before begin()
  
  Bluefruit.configPrphBandwidth(BANDWIDTH_MAX);
  Bluefruit.begin();
  Bluefruit.setTxPower(-4);    // Check bluefruit.h for supported values

  // Initialize Internal File System
  InternalFS.begin();
  
  file.open(WST, FILE_O_READ);
  // file existed
  if ( file ){
      readlen = file.read(buffer2, sizeof(buffer2));
      i=buffer2[readlen-1]-0x30;
      file.close();
      Bluefruit.setName(ad_name[i]);
//      Serial.println(buffer);
  }
  // not file existed
  else{
       file.close();
       file.open(WST, FILE_O_WRITE);          
       file.write("0");
       file.close();
       Bluefruit.setName(ad_name[0]);
  }
  
  //Bluefruit.setName(getMcuUniqueID()); // useful testing with multiple central connections
  Bluefruit.Periph.setConnectCallback(connect_callback);
  Bluefruit.Periph.setDisconnectCallback(disconnect_callback);

  // To be consistent OTA DFU should be added first if it exists
  bledfu.begin();

  // Configure and Start Device Information Service
  bledis.setManufacturer("bFaaaP factory");
  bledis.setModel(Model.c_str());
  bledis.begin();

  // Configure and Start BLE Uart Service
  bleuart.begin();

  // Start BLE Battery Service
  blebas.begin();
  blebas.write(100);

  // Set up and start advertising
  startAdv();

  LED(on,y);

}

void startAdv(void)
{
  // Advertising packet
  Bluefruit.Advertising.addFlags(BLE_GAP_ADV_FLAGS_LE_ONLY_GENERAL_DISC_MODE);
  Bluefruit.Advertising.addTxPower();
  
  // Include bleuart 128-bit uuid
  Bluefruit.Advertising.addService(bleuart);
  
  // Secondary Scan Response packet (optional)
  // Since there is no room for 'Name' in Advertising packet
  Bluefruit.ScanResponse.addName();
  Bluefruit.Advertising.restartOnDisconnect(true);
  Bluefruit.Advertising.setInterval(32, 244);    // in unit of 0.625 ms
  Bluefruit.Advertising.setFastTimeout(30);      // number of seconds in fast mode
  Bluefruit.Advertising.start(0);                // 0 = Don't stop advertising after n seconds 
   
}

void LED(int onoff,uint32_t colors)
{
uint32_t tmp;  
  if(onoff==0)
    strip.setPixelColor(0, colors|color);
  else{
    colors=0Xfffff^colors;
    strip.setPixelColor(0, colors&color); 
  }    
  strip.show(); // Update strip with new contents
  
}

void deep_sleep()
{
       LED(off,g);
       LED(off,m);
       digitalWrite(LED_RED, LOW);
       digitalWrite(13,LOW);         
//       while(digitalRead(A1)==LOW);
       pinMode(WAKE_LOW_PIN,  INPUT_PULLUP_SENSE);    // this pin (WAKE_LOW_PIN) is pulled up and wakes up the feather when externally connected to ground.
       // power down nrf52.
       sd_power_system_off();                         // this function puts the whole nRF52 to deep sleep (no Bluetooth).  If no sense pins are setup (or other hardware interrupts), the nrf52 will not wake up.  
}
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

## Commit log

2026-06-12 Initial commit: bFaaaP open-source bundle (iOS app, Pro/Switch device, docs, arXiv preprint)
    Open-source staging for bFaaaP (barrier-Free assist as a Pedal), an AI assistive
    piano-pedal system. Includes the sanitized iOS controller source + design notes,
    Pro (acoustic) and Switch (electronic) device firmware/hardware/docs, operation
    and toolchain guides, member/video/history docs, and the arXiv preprint LaTeX
    (figures regenerated from photos). Private during preparation; public after review
    and member consent. Patents JP6726319/JP7004771, PCT WO2019/176164.
    [10mm_dai-a.3mf, 10mm_dai-a.stl, 10mm_dai.FCStd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]
2026-06-14 Add patent dossier, revised papers, and imported circuit/CAD; refine device docs
    作業6 (patents): bfaaap_patent_info/ with PCT WO2019/176164 + ISR analysis,
    JP6726319 & JP7004771 prosecution, and a plain-language general_description guide;
    personal addresses redacted from the certificates and ISR transmittal pages.
    作業7 (papers): full logic-level rewrite in two synced versions — arXiv (main.tex)
    and ACM TACCESS (main_taccess.tex) — sharing draft_sections/body.tex; refs.bib
    (~32 refs), new figures (control-vs-prior-art, APEE results), JOURNAL-TARGETS.md.
    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
    [bFaaaP_AA-A.stl, bFaaaP_AA.FCStd, bFaaaP_CC-CC.stl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]
2026-06-14 Papers: add Ootaki as 2nd author + Shishido ORCID; lock in BLE board + co-author consent
    Papers (arXiv main.tex + ACM TACCESS main_taccess.tex):
    - Add Masahiro Ootaki (Ootaki & Architects, Sayama, Saitama 350-1306) as second
    author; order Shishido (corresponding) -> Ootaki -> Narusawa; update COI
    (Ootaki is a co-inventor / Ootaki & Architects a co-patentee) and shortauthors.
    - Make Shishido's ORCID (0000-0002-8944-2088) visible/clickable in both versions.
    Device docs (co-author answers):
    - BLE board confirmed = Akizuki AE-NRF52840 (g117484) (cheaper, same BLE module,
    same board ID); Adafruit Feather nRF52840 is a compatible alternative; not
    ItsyBitsy. Updated PARTS-REFERENCE, HARDWA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
2026-06-14 Add proposed licensing scheme (Apache-2.0 / CERN-OHL-W / CC-BY) across repo and papers
    Proposed (pending final decision), marked as such everywhere:
    - Software (iOS app, firmware) -> Apache License 2.0 (explicit patent grant)
    - Hardware (CAD, 3D-print, schematic) -> CERN-OHL-W-2.0 (alt. CERN-OHL-S / CC-BY-SA-4.0)
    - Documentation -> CC-BY-4.0
    Patent practice in a device stays governed by the separate patent policy
    (free for public/inclusive uses).
    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
2026-06-14 Add Pro build photos (airback + drive unit) to the hardware docs
    New device-pro-acoustic/hardware/photos/ gallery (from the team Discord, by
    R. Taguchi; no people/PII): disassembled Pro showing the blue air-pump wedge
    (airback) + aluminium drive unit + motor/boards, the airback air valve, the I/O
    panel (RJ45/toggle/8-pin power), the 8-pin power connector, and the 3D-printed
    panels. Embedded the airback + valve shots in hardware/airback/README.md, linked
    the gallery from hardware/README.md, and added a photo-consent item (Taguchi) to
    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
2026-06-21 docs: add Q&A figures for discussions #2 (Pico editors) and #3 (signal flow, pedal force)
    Generated by AI-assisted support (matplotlib charts/tables + Gemini illustration).
    AI illustration © Shishido & Associates; charts CC BY 4.0.
2026-06-21 docs(S2+S3): rewrite README front door + add iOS/Pro/Switch build guides
    - README.md: story-driven front door (hero + illustrations + nav to story/how-it-works/
    glossary/build/ai-support/SUPPORT); fix stale TACCESS ref (arXiv-only); import architecture/
    pro-mechanism/rate-decoupling diagrams; no bfaaap.com image hotlinks
    - docs/build/{ios,pro,switch}.md: step-by-step imperative guides (per-step parts, ASCII
    flowcharts, photos, links); build hub links them
    - Draft quality; pending maker specifics flagged as TODO
2026-06-21 docs(build): track docs/build/ guides (gitignore 'build/' was swallowing them)
    Fix .gitignore to exempt docs/build/, then add the iOS/Pro/Switch build guides + hub that
    were silently ignored. Story/README links to docs/build/ now resolve.
2026-06-21 docs(S5): add SOURCE-MAP (file/figure/code index), control-law + build-flow figures, CAD-derived mechanical BOM
    - docs/SOURCE-MAP.md: explicit index mapping each topic -> its files (CAD/STL/schematic/code/photo/figure) with paths
    - docs/media/diagrams/control-law.png (head-angle->pedal) embedded in how-it-works
    - docs/media/diagrams/pro-build-flow.png (8 steps -> files) + CAD-derived mechanical BOM table in build/pro.md
    - link SOURCE-MAP from README + build hub
2026-06-21 docs: display 田口 as surname-only 'Taguchi' (his standing request; drop 'R.'/'Reo')
    Apply to non-WIP files (PARTS-REFERENCE, media/CREDITS); members/story already surname-only.
    WIP-stashed files (PUBLISHING-CHECKLIST, DISCORD-FINDINGS, hardware READMEs, LICENSE) still
    have 'R./Reo Taguchi' — to fix when the maintainer WIP is reconciled.
2026-06-21 i18n(ja): add Japanese translations — README, how-it-works, ai-support, SUPPORT (+ i18n/README)
    Mirror under i18n/ja/. Images/code/CAD shared from the English tree (relative links); each page
    has a language switcher. Cross-links to not-yet-translated pages fall back to English.
2026-06-21 i18n: fix link fallbacks (ja GLOSSARY -> EN; de marked pending)
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2026-06-21 i18n(de): add German set (README, how-it-works, ai-support, SUPPORT) + cross-language switchers
    EN/JA/DE now at parity for the core docs. Added 🌐 language switchers to the EN pages and linked
    de from the ja pages + i18n/README. Shared images/code/CAD via relative links (single source).
2026-06-21 i18n(ja+de): add GLOSSARY + build hub/iOS/Switch translations
    Japanese & German for GLOSSARY and the build hub + iOS/Switch guides. (build/pro + story remain.)
    Cross-links use same-language where translated, else fall back to English.
2026-06-21 i18n(ja+de): track build guides (gitignore 'build/' was ignoring i18n/*/docs/build too)
    Fix .gitignore to also exempt i18n/**/docs/build, then add the ja+de build hub/iOS/Pro/Switch
    guides that were silently ignored (same bug as docs/build earlier). Same-language build links.
2026-06-21 i18n(ja+de): add the story; point same-language story/GLOSSARY/build cross-links in-language
    Completes the ja+de translation set (README, story, how-it-works, GLOSSARY, ai-support, SUPPORT,
    build hub+iOS/Pro/Switch). EN/JA/DE now fully at parity.
2026-06-21 docs(i18n): add 🌐 language switchers to remaining EN pages (story, glossary, build/*)
    EN/JA/DE tri-lingual docs complete and cross-linked. 0 broken links.
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2026-06-24 arXiv paper revision + tri-lingual docs (abstract, airback, GP1→GC1, citations, global accessibility impact)
    Paper (bfaaap_arxiv_latex, now 27pp, refs verified June 2026):
    - Abstract rewritten to fit arXiv 1920-char + ACM ~250-word limits, foregrounding the
    control-law "key", the AR↔BLE trick, the airback non-destructive anchoring, and concert use.
    - "airback" defined as a coined term (vs "airbag") in abstract + sec:airback.
    - APEE piano model GP1 corrected to GC1 (Yamaha); Pico GPIO GP0/GP1/GP12/GP13 untouched.
    - All 50 references verified against primary sources; 9 metadata errors fixed; 5 former
    orphans now cited (PCT + ISR prior art).
    - Inclusive-impact population globalised: new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
2026-06-24 device docs: add Switch firmware (Narusawa) + confirm Pro schematic & import KiCad (Taguchi)
    Switch (Narusawa, sketch dated 2021-10-07, contributed 2026-06-24):
    - add standalone nRF52 BLE firmware at device-switch-electronic/firmware/
    (Nordic UART on/off via GP13, channels bFaaaPSwitch_1..4, on/off-mode
    polarity, deep-sleep/wake on A1) + an analysis README
    - wire it into the Switch device README, firmware CODE-STRUCTURE, the
    build/switch guide and SOURCE-MAP (all en/ja/de)
    Pro electrical (Taguchi reply 2026-06-24 confirming the KiCad schematic):
    - correct the BLE board: Pro = Akizuki AE-NRF52840 (Adafruit Feather = option),
    NOT the ItsyBitsy (the ItsyBitsy/DotStar is the Switch's bo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
    [bFaaaP.kicad_pcb, bFaaaP.kicad_sch]
2026-06-24 firmware: consolidate Narusawa's Switch sketch to device-switch-electronic/
    Narusawa uploaded bFaaaPSW_20211007_for_ex_fs_J_13_ymc.ino to
    device-pro-acoustic/firmware/pico/ (his note: there was no Switch firmware
    location, so he put it under pico/). The same sketch is now correctly located
    and documented at device-switch-electronic/firmware/ (Arduino sketch folder +
    analysis README), so remove the misplaced duplicate from the Pro pico/ folder.
    Byte-identical; no docs referenced the old path.
    [bFaaaPSW_20211007_for_ex_fs_J_13_ymc.ino]
2026-06-24 device-switch: record Narusawa's Switch hardware answers (2026-06-24)
    Narusawa confirmed the remaining Switch hardware details:
    - GP13 switching element is a MOSFET (not a relay/opto), with no series resistor
    - board = Adafruit ItsyBitsy nRF52840 Express
    - no A1 button in the built device -> power on / wake with RESET
    - powered by 2x AA cells (replaceable, not USB-rechargeable); battery level
    shown by the onboard DotStar dimming
    - the 2021-10-07 sketch is the final/current firmware
    Reflected in device-switch-electronic/README.md, firmware/README.md, and the
    build/switch guide (en/ja/de): relay/optocoupler -> MOSFET, board = ItsyBitsy,
    AA power, on/off-mode polarity. Only the exact MOSFET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
2026-06-24 hardware/reference: replace unknown-license images with original drawings
    Taguchi flagged (2026-06-24) that the two images carried over from the legacy
    bfaaapteam docs/hardware.md were brought in from elsewhere with unknown license:
    - rpi_pico_pinout.svg
    - fortiq42_electrical-interface.png (IQ Motion Control vendor figure)
    Remove both and replace with original bFaaaP-project matplotlib drawings
    (CC BY 4.0), redrawn from the public/factual pinouts:
    - pico_pinout_bfaaap.png Raspberry Pi Pico, bFaaaP Pro nets highlighted
    - fortiq42_interface_bfaaap.png IQ Fortiq BLS42 connector + bFaaaP wiring
    (does not assert exact serial pins; points to Vertiq docs)
    Update references in PA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
2026-06-24 device-switch/assembly: add AI-draft 3D-printable enclosure (SCAD + STL + drawing)
    Simple, adaptable 2-part case for the whole Switch (ItsyBitsy nRF52840 + 2x AA
    holder + RU1J002YN), drafted from the known internals:
    - switch-enclosure.scad — parametric OpenSCAD source (edit + export STL)
    - switch-enclosure-base.stl / -lid.stl — watertight/manifold, ready to slice
    - switch-enclosure-reference.png — dimensioned reference drawing (matplotlib)
    - README — features, print settings, assembly steps
    2-layer stack (AA holder on the floor, board on shelf ledges); lift-off lid for
    battery swaps; DotStar LED window; RESET access hole (= power-on/wake); cable
    U-notch to the 6.3 mm TS plug; USB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
    [switch-enclosure-base.stl, switch-enclosure-lid.stl, switch-enclosure.scad]
2026-06-24 docs/build/switch: finalise the MOSFET note (RU1J002YN + reference circuit)
    The Switch hardware is complete, so replace the stale "being finalised" notes in
    Step 2 (en/ja/de) with the confirmed part (ROHM RU1J002YN) and a link to the
    reference circuit in device-switch-electronic/hardware/.
2026-06-24 device-pro/airback: identify the airback as a WINBAG air jack (specs + where to buy)
    From the device photos (devicePRO_photos) + a product match, the airback is an
    off-the-shelf inflatable air jack — a WINBAG (the blue handheld air wedge/cushion):
    160 x 150 mm, inflates up to 50 mm, 135 kg capacity, 79 g, with a hand squeeze-bulb
    pump + bleed valve. So it is NOT fabricated — you buy one.
    - airback/README: full identification, official specs table, a matplotlib
    reference drawing (airback-dimensions.png), and where to buy (JP: Amazon.co.jp /
    monotaro / Komeri / shun-ei; intl: Toolstation/Lowe's/Amazon; Winbag/Rhino/Gute).
    - assembly BOM: replace the rough "air jack 119 x 11 cm" with t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
2026-06-24 device-pro/reference-design: add AI-draft electronics-box enclosure + example part links
    - pro-ebox.scad + pro-ebox-base.stl/-lid.stl: a simple, adaptable 2-part case for the
    Pro electronics (Pico + nRF52840 + MOSFET/terminals) — cable U-notches, two USB slots,
    4 board standoffs, screw-down lid (watertight). The motor mount / lead-screw blocks /
    push-rod guide stay separate (motor-dependent).
    - README: "Suggested parts — examples only" table (Amazon/AliExpress/maker search links
    for the adaptable parts) with a prominent disclaimer that these are AI-listed
    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
    [pro-ebox-base.stl, pro-ebox-lid.stl, pro-ebox.scad]
2026-06-24 figures: legibility + dpi 300 pass (architecture/mechanical redesigned)
    Improve readability of the AI-draft diagrams (per review feedback): bigger fonts,
    removed text/box overlaps, and re-rendered all reference figures at dpi 300:
    - pro-architecture.png / pro-mechanical-layout.png — larger fonts, spaced layout,
    fixed slider/Pico, force-feedback, legend, and label overlaps
    - airback-dimensions.png, reference/pico_pinout_bfaaap.png,
    reference/fortiq42_interface_bfaaap.png, switch-enclosure-reference.png — dpi 300
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2026-06-26 docs/media: credit member portraits/avatars as Saki Shiokawa's ORIGINAL hand-drawn art (not 'style')
    The member portraits/caricatures and the round member avatars (face-crops of her originals) are
    Saki Shiokawa's own hand-drawn works → '© Saki Shiokawa', not 'Saki Shiokawa style'. Only the
    scene/hero illustrations and the AI-assistant avatar (ai.png) are Gemini-generated in her style
    (© Shishido & Associates); those keep the 'style' wording. Fixes the mislabels in avatars/README,
    CREDITS, ai-team-live and the motor-choice example.
2026-06-30 docs+papers: finalize EN, full JA/DE i18n, Voices, figures, BOM-updated papers
    Papers (arXiv + shared sections):
    - Updated BOM: vertical drive (2040/2080/4040, GT-2 262 belt, T60/T60 1:1, T10
    screw), motor IQ/Fortiq M42BLS -> closed-loop NEMA17 successor (under
    evaluation; dropped DRV8825), WINBAG airback, Switch ItsyBitsy nRF52840 +
    ROHM RU1J002YN low-side MOSFET / 2xAA / reset.
    - New Discussion subsection "Future perspectives" (Narusawa); Taguchi added to
    Acknowledgements; Table 1 offset/multiplier ranges reconciled with the
    appendix (multiplier I 10-40, III 8-50); flow/consistency pass; recompiles 0
    errors.
    English finalized:
    - Canonical control-law wording everywhere (offset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
2026-07-01 docs(voices): restore former Platanus president "Yoshida" in Shishido's origin story (consent obtained)
    Yoshida (ex-Platanus president, non-member) consented 2026-07-01 to being
    named in the founder's origin story. Restore surname-only "Yoshida" in all
    three languages of docs/voices/shishido.md:
    - JA: 当時の部長 → 当時部長の吉田(Yoshida)さん
    - EN: the then-president → the then-president Mr. Yoshida
    - DE: der damalige Vorsitzende → der damalige Vorsitzende Herr Yoshida
    Mark the PENDING-SUPPLEMENTS "Yoshida" pre-publication item resolved.
    (Consent evidence + log kept private, outside this repo.)
2026-07-02 docs: AI teammates (Ponte & Harmonia), full second-AI sensing transcript, kyoko member
    Adds the "AI & Team, Live" second-AI thread and two named AI teammates, plus a new
    human member, across EN/JA/DE (+ mirrored on bfaaap.com):
    - Act 8 "two AIs, one problem": the project AI (Ponte) and a second AI (Harmonia)
    compare notes on sensing; hero illustration + link to the full transcript.
    - Full verbatim Narusawa x Harmonia transcript (ai-support-example-second-ai-sensing.md,
    EN/JA/DE) — asymmetric fast-release, gyro release-detection, the T2 reference-sensor
    idea, and MicroPython/C++/Arduino drafts. Clearly flagged UNVERIFIED external-AI input.
    - Two AI members with their own self-introdu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
2026-07-03 docs: fix current-gen label (bFaaaP 4→6), add Ootaki voice + AI-collab art
    - History figures: relabel the current device "Today · bFaaaP 4" → "bFaaaP 6"
    (bFaaaP 4 = the earlier APEE-era wooden-enclosure prototype) in
    the-invention-from-the-start and then-vs-now-sensor-and-motor, regenerated
    clean from the canonical generators; fix the matching alt text in the
    invention README (EN/JA/DE). The APEE data-table "bFaaaP4/bFaaaP4W" entries
    are left unchanged (correct historical usage).
    - Voices: add Masahiro Ootaki's message (docs/voices/ootaki.md, JA verbatim +
    EN/DE) and a card in the Voices overview (EN + i18n ja/de).
    - Add the Ponte × Harmonia AI-collaboration illustration (m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
2026-07-04 docs(live): Act 7 continuation — Narusawa answers Tanaka on press-force sensing (EN/JA/DE)
    Narusawa replies to Tanaka's Act 7 question: no separate sensor needed —
    the gap between commanded and actual rotor position is the press-force proxy,
    read over the RX/TX (UART) lines (option A / following-error). Tanaka follows
    up and invites Ponte, who adds a study note on the deviation-detection
    algorithm. Reflected in ai-team-live.md + ai-support-example-pro-motor.md and
    the Finale beat, across English, Japanese, and German.
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2026-07-04 app name: unify to 'bFaaaP Pro & Switch' (drives both Pro and Switch)
    The app runs both the Pro and the Switch, so name it accordingly. Avoid '/'
    (a path/URL separator that can misbehave); '&' is safe in a display/App Store
    name. Updates the on-device CFBundleDisplayName + the app-store listing metadata
    + README references (EN/JA/DE). NOT changed: the BLE device names
    'bFaaaPSwitch_n' (firmware) and the Xcode target 'bFaaaPSwitch1'.
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2026-07-13 docs(arxiv): final review edits + Ootaki author line + APEE ethics section
    - body.tex Sec3.2: distinguish recommended range vs measured Table-1 range
    (Harmonia final review); main.tex date; recompile main.pdf (0 errors).
    - README (root + arxiv): author line = Shishido, Ootaki, Narusawa.
    - apee-study.md (en/ja/de): add Ethics section (voluntary written informed
    consent for adults/children/participants with disabilities; no IRB;
    ACM research-ethics policy; all data anonymized No.1–15).
2026-07-15 docs(coc): CoC v1 — note Berlin Code of Conduct / Contributor Covenant basis + "will evolve" (EN/JA/DE)
    Phase A of the lean launch: the CoC + join-the-community onboarding already existed and
    match the lean 技術/音楽 (+General/Announcements) category set; this adds a short attribution
    (Berlin Code of Conduct / Contributor Covenant) and a "version 1, evolves with moderators" line,
    honoring Taguchi's Issue #6 suggestion.
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2026-07-22 docs(paper): repo reference now reflects the public repository
    The `repo` bib entry still said "the repository is made public on release",
    which has been stale since bfaaap_opensource went public on 2026-07-16.
    Reworded to "Public open-source repository (iOS app, firmware, CAD,
    documentation)" and recompiled main.pdf (28 pp, 0 errors).
    Kept in sync with the TACCESS copy of refs.bib, where the same entry also
    had the outdated TomoShishido/ URL (fixed there for the 2026-07-23
    resubmission; the arXiv copy already used the bfaaap/ org path).
    Claude-Session: https://claude.ai/code/session_013rdZ1cdoLGh3MAntpfXYGf

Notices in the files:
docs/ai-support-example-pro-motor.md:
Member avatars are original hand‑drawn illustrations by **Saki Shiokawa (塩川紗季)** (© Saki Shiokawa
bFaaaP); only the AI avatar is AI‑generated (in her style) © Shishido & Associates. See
